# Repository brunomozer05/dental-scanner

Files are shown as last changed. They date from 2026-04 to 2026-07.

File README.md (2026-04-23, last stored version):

# DentalScanner

Aplicativo iOS nativo em Swift para capturar tags ArUco com a camera do iPhone, estimar a pose 3D dessas tags via fotogrametria/visao computacional e gerar um arquivo `.stl` com a posicao final das tags no espaco.

Este repositorio agora contem a fundacao do projeto:

- Arquitetura modular alinhada a captura ArUco + export STL
- App iOS em SwiftUI com fluxo demo de captura guiada
- Camada `DentalScannerKit` com Core, ArUco, Photogrammetry e Export
- Testes unitarios iniciais para validacao de sessao, tags, STL e fusao das poses
- GitHub Actions com geracao de projeto via XcodeGen
- Documentacao tecnica e assets de calibracao

Importante: esta primeira iteracao prioriza arquitetura, contratos e automacao. O backend real de deteccao ArUco via OpenCV e a estimacao/fusao de poses em producao ainda precisam ser conectados.

## Objetivo real do app

Fluxo esperado:

1. O usuario aponta a camera do iPhone para um conjunto de tags ArUco.
2. O app detecta as tags quadro a quadro.
3. O pipeline estima a pose 3D das tags e funde observacoes de multiplas vistas.
4. Ao finalizar, o app gera um `.stl` contendo a representacao 3D das tags nas posicoes estimadas.

Este projeto nao esta sendo tratado, neste momento, como uma reconstrucao detalhada de uma superficie odontologica. O foco da base atual passou a ser mapa 3D das tags ArUco.

## Requisitos de produto

- iOS 15.0+
- iPhone 8 ou superior
- Camera RGB 12 MP ou superior
- Sem uso de LiDAR
- Tags ArUco 4x4_50 ou 4x4_100 com 8 mm x 8 mm
- Meta de precisao final: +-100 um

## Estrutura do repositorio

```text
DentalScanner/
|- App/
|- UI/
|- Core/
|- ArUco/
|- Photogrammetry/
|- Export/
|- Shared/
|- Support/
Tests/
docs/
Resources/
.github/workflows/
project.yml
```

## Setup do ambiente

### Opcao 1: abrir em um Mac com Xcode

1. Instale Xcode 15.2 ou superior.
2. Instale XcodeGen:

```bash
brew install xcodegen
```

3. Gere o projeto:

```bash
xcodegen generate
```

4. Abra `DentalScanner.xcodeproj` no Xcode.
5. Rode o scheme `DentalScanner` em um simulador iPhone ou dispositivo fisico.

### Opcao 2: usar apenas GitHub Actions

O workflow em `.github/workflows/ios-build.yml`:

- instala Xcode 15.2
- instala XcodeGen
- gera o projeto
- roda build
- roda testes
- gera sempre um `.ipa` unsigned como artifact
- gera tambem um `.ipa` assinado quando os secrets de assinatura estiverem configurados

## Gerar `.ipa` no GitHub Actions

Agora existem dois formatos de artifact:

- `DentalScanner-IPA`: sempre gerado, no mesmo estilo do seu outro projeto, com `.ipa` unsigned
- `DentalScanner-Signed-IPA`: opcional, apenas quando os secrets de assinatura estiverem configurados

Importante: o `.ipa` unsigned serve para baixar o arquivo pronto do GitHub, mas nao instala diretamente no iPhone sem assinatura posterior.

### Secrets obrigatorios

Cadastre em `Settings > Secrets and variables > Actions`:

- `BUILD_CERTIFICATE_BASE64`: conteudo Base64 do certificado `.p12`
- `P12_PASSWORD`: senha do `.p12`
- `BUILD_PROVISION_PROFILE_BASE64`: conteudo Base64 do `.mobileprovision`
- `KEYCHAIN_PASSWORD`: senha temporaria do keychain usado no runner
- `APPLE_TEAM_ID`: Team ID da sua conta Apple Developer

### Variable opcional

Cadastre em `Settings > Secrets and variables > Actions > Variables`:

- `IOS_EXPORT_METHOD`: `development` ou `ad-hoc`

Se nada for definido, o workflow usa `development`.

### Como converter os arquivos para Base64

No Mac:

```bash
base64 -i Certificates.p12 | pbcopy
base64 -i Profile.mobileprovision | pbcopy
```

No Windows PowerShell:

```powershell
[Convert]::ToBase64String([IO.File]::ReadAllBytes("Certificates.p12"))
[Convert]::ToBase64String([IO.File]::ReadAllBytes("Profile.mobileprovision"))
```

### Requisitos para instalar no celular

- o `Bundle Identifier` do app precisa bater com o provisioning profile
- o iPhone precisa estar incluido no profile se o metodo for `development` ou `ad-hoc`
- o certificado precisa pertencer ao mesmo time Apple do profile

### Onde baixar o `.ipa`

Depois do workflow terminar:

1. abra a execucao no GitHub Actions
2. entre em `Artifacts`
3. baixe `DentalScanner-IPA` para o `.ipa` unsigned
4. se houver, baixe `DentalScanner-Signed-IPA` para o build assinado

O artifact inclui:

- um `.zip` gerado automaticamente pelo GitHub Actions

Dentro do `.zip` do artifact ficam:

- `DentalScanner.ipa`

No artifact assinado tambem pode haver:

- plist(s) de exportacao
- `DentalScanner.xcarchive`

### Como instalar

Com o `.ipa` assinado em maos, voce pode instalar via:

- Xcode
- Apple Configurator 2
- MDM
- TestFlight, se depois trocar o metodo para distribuicao adequada

## Como calibrar a camera

1. Imprima o tabuleiro `10x7` em escala conhecida.
2. Use iluminacao uniforme e evite reflexos especulares.
3. Capture de 30 a 50 imagens com variacao real de angulo e distancia.
4. Garanta o tabuleiro inteiro visivel em todos os frames.
5. Aceite a calibracao somente quando o erro medio de reprojecao ficar abaixo de `0.3 px`.
6. Persista a calibracao por dispositivo.

Assets de apoio:

- `Resources/CalibrationTargets/checkerboard_10x7.svg`
- `Resources/SampleCalibrationDataset/manifest.json`

## Como posicionar as tags ArUco

- Use 4 a 8 tags simultaneas.
- Tamanho fisico de cada tag: `8 mm x 8 mm`.
- Distribua as tags ao redor do fixture para manter pelo menos 4 visiveis em quase toda a orbita.
- Evite oclusao por dedos, pinas ou suportes.
- Mantenha as tags no mesmo plano de referencia global sempre que possivel.
- Prefira imprimir em material matte para reduzir reflexos.

## Fluxo de captura planejado

1. Carregar calibracao valida.
2. Posicionar o setup com as tags visiveis.
3. Capturar de 15 a 30 poses ao redor do conjunto de tags.
4. Garantir sobreposicao de 70-80% entre frames consecutivos.
5. Validar nitidez, blur, iluminacao e visibilidade de tags em tempo real.
6. Estimar e fundir as poses 3D das tags entre multiplos frames.
7. Gerar STL com a posicao final das tags + relatorio.

## Estado atual da implementacao

Ja implementado:

- `CameraEngine` com configuracao de captura de alta precisao via `AVFoundation`
- `CalibrationManager` para avaliar e persistir intrinsecos
- `SessionManager` com cobertura angular, quality gates e progresso
- `ArUcoDetector` com interface pronta para backend OpenCV
- `TagValidator` e `PoseEstimator`
- `MarkerSceneReconstructor` para fundir observacoes por ID de tag
- `MeshReconstructor` configurado para gerar malha STL das tags
- `STLExporter` e `MeasurementReportGenerator`
- UI demo em SwiftUI para provar o fluxo

Proximo passo tecnico obrigatorio:

- integrar um backend real de OpenCV para deteccao ArUco e `solvePnP`
- estimar pose 6DoF real por tag com intrinsecos calibrados
- fundir as poses entre multiplas imagens com rejeicao de outliers
- exportar o STL final direto no iPhone
- validar a consistencia espacial entre tags

## Debug mode recomendado

Manter um modo debug com:

- IDs das tags visiveis por frame
- score de nitidez
- score de overlap
- mapa de cobertura angular
- contagem de features detectadas
- pares aceitos/rejeitados no matching
- mapa de calor de erro no pos-processamento

## Troubleshooting

### Nao detecta tags

- Verifique impressao das tags.
- Aumente iluminacao difusa.
- Evite motion blur.
- Confirme se 4 ou mais tags estao inteiras no frame.

### Reconstrucao instavel

- Refaca a calibracao se o erro passar de `0.3 px`.
- Aumente a sobreposicao entre capturas.
- Capture em orbita mais lenta.
- Remova frames com brilho especular excessivo.

### Escala incorreta

- Confirme dimensao fisica real das tags.
- Verifique se o backend de pose usa pontos-objeto em milimetros.
- Rejeite tags com escala inconsistente.

### Build do CI falha

- Verifique se o `project.yml` foi atualizado junto com novos arquivos.
- Rode `xcodegen generate` antes do build local.
- Confirme a versao do Xcode no workflow.

## Documentacao tecnica

- [Pipeline de Fotogrametria](docs/photogrammetry-pipeline.md)
- [Estrategia de Precisao](docs/precision-strategy.md)
- [Formato de Dados](docs/data-format.md)

## Roadmap sugerido

1. MVP com deteccao ArUco e STL basico das tags
2. Integracao OpenCV + pose 6DoF real
3. Fusao robusta de poses entre multiplas vistas
4. Exportacao STL final no aparelho
5. Refinamento de precisao para meta de +-100 um

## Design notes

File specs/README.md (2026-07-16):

# DentalScanner Specs

Esta pasta contém as specs oficiais do projeto DentalScanner.

Antes de qualquer alteração no código, o agente deve ler:

1. `00_project_context.md`
2. `08_known_issues.md`
3. `09_next_tasks.md`
4. A spec específica da área que será alterada

Estas specs são a fonte de verdade do projeto.

## Indice

* `00_project_context.md` - contexto geral do projeto.
* `03_scan_pipeline.md` - pipeline principal de scan/export.
* `05_pose_quality_and_readiness.md` - qualidade de pose e readiness.
* `06_export_and_reports.md` - export STL e reports.
* `07_debug_panel.md` - regras do debug seguro.
* `08_known_issues.md` - problemas conhecidos.
* `09_next_tasks.md` - backlog tecnico.
* `10_best_final_pose_candidate.md` - plano futuro para exportar o melhor candidato de pose final.
* `11_device_quality_pipeline.md` - perfis por device, frame mask e quality diagnostics.
* `12_observation_quality_and_angle_diversity.md` - qualidade de observacoes e diversidade angular.
* `13_camera_resolution_focus_intrinsics.md` - camera, foco, resolucao e intrinsics.
* `14_marker_v3_and_robust_pnp.md` - marker futuro, pontos extras e PnP robusto.
* `15_validation_protocol_and_accuracy.md` - protocolo de validacao e limites das afirmacoes de accuracy.
* `16_frame_indexed_observations.md` - Frame Indexed Observation Model.
* `17_pre_accumulation_observation_gate.md` - Pre-Accumulation Observation Quality Gate.
* `18_scan_session_replay.md` - Scan Session Capture and Deterministic Replay.
* `19_frame_indexed_bundle_adjustment.md` - active frame-indexed bundle-adjustment investigation and implementation plan.
* `19_offline_frame_indexed_optimization.md` - historical optimizer roadmap, superseded by the detailed Spec 19A design.
* `20_capture_maturity_replay.md` - offline capture-maturity, angular-diversity, connectivity, and progress replay.

## Regras gerais

* Não reativar código antigo de debug que já causou crash.
* Não alterar OpenCV, solvePnP, STLExporter ou GitHub Actions sem necessidade explícita.
* Não copiar código, assets, modelos ou algoritmos de terceiros.
* Não usar arquivos de apps externos dentro do projeto.
* Manter o pipeline atual funcional.
* Toda alteração deve ser incremental, segura e fácil de reverter.
* Se algum dado for inválido, nil, NaN ou infinity, a UI deve mostrar `—`, nunca crashar.

## Ordem recomendada das próximas tarefas

1. Bloquear export STL se houver menos de 4 markers exportáveis.
2. Melhorar câmera/foco/sharpness.
3. Atualizar comparador Python para ler `_report.json`.
4. Comparar iPhone 11 vs iPhone 16 com dados objetivos.
5. Comparar marker v1 vs marker v2.
6. Avaliar marker v3 híbrido futuramente.
7. Adicionar ARKit Assist experimental.
8. Refinar final pose/export quality gates.

## Roadmap arquitetural frame-indexed

As specs 16–20 seguem a ordem abaixo. As fundações diagnostics/shadow 16–17, as phases 18A/18B, o replay offline ALL/Pre-Gate persistido e o export diagnóstico de STLs ALL/FILTERED em frame comum estão implementados. A Spec 20 adiciona validação offline de maturidade da captura antes de qualquer mudança no progresso ao vivo. A Spec 19A está especificada; validação física dos replays, blocking ao vivo e implementação 19B permanecem pendentes.

### Phase A

`16_frame_indexed_observations.md`

Criar a fundação diagnostics/read-only que preserva a associação entre frame, intrinsics, correspondências e pose por frame.

### Phase B

`17_pre_accumulation_observation_gate.md`

Avaliar e, atrás de feature flag desligada por padrão, impedir que observações rejeitadas entrem no acumulador primário.

### Phase C

`18_scan_session_replay.md`

Persistir sessões geométricas versionadas para replay determinístico e comparação A/B sobre os mesmos dados.

### Offline maturity checkpoint

`20_capture_maturity_replay.md`

Reproduzir offline a maturidade por marker e global sobre o mesmo schema-1, separando observações ALL/FILTERED, vistas distintas, cobertura, conectividade e timeline. `STRICT` permanece o resultado principal; um modo `REFERENCE_LIKE` documenta relaxamento adaptado sem afirmar a fórmula protegida da referência.

Esse diagnóstico deve ser executado sobre sessões físicas antes de alterar a barra ao vivo ou escolher a população de frames da futura Spec 19C. Ele não implementa BA e não conclui 19B.

### Phase D

`19_frame_indexed_bundle_adjustment.md`

Investigar, especificar e depois comparar offline o acumulador atual com um bundle adjustment que mantém uma pose de câmera por frame e uma pose compartilhada por marker. A implementação começa em 19B somente após revisão da Spec 19A; qualquer população selecionada pelo replay de maturidade exige validação física antes de virar uma política da futura 19C.

Somente depois dessas validações avaliar integração primária de diversidade angular, pose graph, marker v3 e otimização global.

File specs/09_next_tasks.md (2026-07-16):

# 09 — Next Tasks

## Prioridade 1 — Bloquear export com menos de 4 markers

Problema:

```txt
às vezes o app exporta STL com 3 markers mesmo parecendo ter escaneado 4.
```

Tarefa:

* separar visual markers de exportable markers;
* definir `expectedPhysicalMarkerCount = 4`;
* bloquear export se `exportableMarkers.count < 4`;
* mostrar erro claro;
* mostrar markers faltando;
* atualizar report JSON.

Commit sugerido:

```txt
Block STL export when markers are missing
```

## Prioridade 2 — Atualizar comparador Python para ler `_report.json`

Tarefa:

* carregar reports junto com STLs;
* comparar poses por marker;
* mostrar qualidade por scan;
* mostrar missing markers;
* mostrar focus/sharpness;
* cruzar erro STL com qualidade reportada.

## Prioridade 3 — Melhorar câmera/foco/sharpness

Tarefa:

* wide física fixa;
* zoom digital controlado;
* foco manual;
* foco guiado por ArUco;
* lock after focus;
* sharpness/blur score;
* rejeitar frames fora de foco;
* debug camera/focus.

## Prioridade 4 — Testes iPhone 11 vs iPhone 16

Fazer pastas:

```txt
tests/iphone11_perto
tests/iphone11_longe
tests/iphone16_auto_focus
tests/iphone16_focus_locked
```

Para cada teste:

* 3 a 5 scans;
* guardar STL;
* guardar report JSON;
* rodar comparador;
* anotar distância/foco/zoom/configs.

Adicionar tambem testes por `cameraProfileId`:

```txt
Default
Wide 1.0x
Wide 1.5x
Wide 2.0x
Wide 1.5x Conservative Focus
Wide 2.0x Conservative Focus
```

Nos testes iniciais do iPhone 16:

* priorizar `Wide 1.5x` como recomendado para `iPhone17,*`;
* testar distância ideal inicial de 150-180 mm;
* evitar ficar abaixo de 120-125 mm, pois aumenta risco de perda de foco;
* manter `Wide 2.0x` e `Wide 2.0x Conservative Focus` como experimentais/não recomendados até nova evidência.
* confirmar no app que a barra lateral de distancia mostra 150-180 mm dentro da faixa verde e usa escala dinamica do perfil.

Proxima etapa futura:

```txt
Auto Camera Profile Evaluation
```

Esse modo deve testar perfis por uma janela curta e escolher o melhor usando:

* markerDetectionRate;
* averageSharpness;
* averageReprojection;
* poseQuality;
* focusLostCount;
* relativeMarkerDistanceStdMean;
* relativeMarkerDistanceStdMax.

Nao automatizar antes de comparar resultados por aparelho/perfil nos reports.

Fases ja implementadas como diagnostics/read-only:

```txt
DeviceQualityProfile por classe de device
Frame Mask / ROI Quality Diagnostics
Experimental Quality Mode com observacoes uteis em paralelo
```

Ainda pendente:

* validar os contadores de observacoes uteis contra CSVs e scans reais;
* adicionar diagnostics completos de diversidade angular;
* adicionar PnP robustness diagnostics;
* atualizar o comparador para expor os novos campos;
* decidir, com dados, se ROI/observacao util vira soft gate.

O replay offline de maturidade da Spec 20 agora separa observações válidas, vistas distintas, frames selecionados, conectividade e o alvo global de 300 frames. Os valores de 65/1,5°/4,5°/300 permanecem parâmetros diagnósticos com proveniência explícita e não alteram export, readiness, finalização ou progresso ao vivo.

High Resolution Camera Profile esta preparado para teste manual e permanece desligado por padrao. Quando `Wide 1.5x High Resolution Experimental` for selecionado manualmente, o app deve tentar 3840x2160 e registrar fallback se o formato nao estiver disponivel.

Reference Camera Matrix Diagnostics e read-only e nao substitui os intrinsics reais da camera.

## Prioridade 5 — Comparar v1 vs v2

Objetivo:

Decidir se o `dualArucoV2` realmente melhora.

Se v1 for mais consistente, considerar voltar foco para v1 ou criar v3 híbrido.

## Prioridade 6 — ARKit Assist experimental

Adicionar ARKit como diagnóstico/quality score, não substituição.

Padrão desligado.

Usar para:

* tracking state;
* camera transform;
* intrinsics;
* motion;
* light estimate;
* penalizar frames ruins.

## Prioridade 7 — Final refinement mais rígido

Tarefa:

* usar quality score centralizado;
* rejeitar blur/foco;
* rejeitar missing markers;
* normal outlier;
* pesos separados posição/rotação;
* confiança final por marker.

## Prioridade 8 — Marker v3 híbrido

Futuro:

```txt
1 ArUco maior
+ bolinhas/pontos
+ fundo branco
+ elementos pretos
```

Não implementar antes de estabilizar v1/v2 e câmera.

## Tarefa futura - Best Final Pose Candidate

Implementar a spec `10_best_final_pose_candidate.md`.

Objetivo:

* durante o refinamento apos 4 markers em 100%, avaliar candidatos com throttle;
* salvar o melhor conjunto de poses final encontrado;
* exportar usando esse melhor candidato quando valido;
* manter fallback seguro para o fluxo atual;
* registrar uso, score, idade e metricas do candidato em diagnostics/report;
* expor campos simples no debug emergencial.

Commit sugerido:

```txt
Add best final pose candidate tracking
```
## Task - Validate high resolution frame processing

Run side-by-side scans with `Wide 1.5x` and
`Wide 1.5x High Resolution Experimental`.

Use the new diagnostics to compare:

```txt
cameraFramePixelBufferWidth/Height
cameraFrameProcessingWidth/Height
cameraFramesReceived/Processed/Dropped
cameraLastFrameProcessingMs
cameraAverageFrameProcessingMs
arucoDetectedMarkerCountLastFrame
arucoDetectedExpectedMarkerCountLastFrame
arucoFramesWithAnyMarkerCount
arucoFramesWithExpectedMarkerCount
poseAcceptedLastFrame
poseRejectedLastFrame
poseLastRejectReason
```

Only consider downscale or intrinsics/corner scaling if the diagnostics prove
that 4K frames arrive but detection or pose acceptance fails.

## Roadmap arquitetural — observações e otimização multi-frame

As próximas fundações arquiteturais devem ser executadas em commits separados. A primeira fase diagnostics-only da Phase A, o shadow diagnostics da Phase B, as fases 18A/18B da Phase C e os replays offline A/B estão implementados. Blocking ao vivo permanece desligado. A Spec 20 fornece o checkpoint offline de maturidade da captura; a implementação BA da Phase D permanece pendente.

### Phase A — Spec 16

`16_frame_indexed_observations.md`

Adicionar um modelo de observação por frame, inicialmente diagnostics/read-only, preservando:

```txt
frame index e timestamp
intrinsics e dimensões do frame
observações por marker
correspondências 2D/3D
pose individual por frame
quality metadata
```

Não alterar acumulador, readiness, finalization ou export nessa fase.

Status: primeira fase diagnostics-only implementada em 2026-07-12, com modelo explícito por frame, buffer limitado, diagnostics agregados e reset de sessão. A captura full-session passou à Phase 18A; reader/replay e qualquer consumo pelo pipeline primário permanecem pendentes.

### Phase B — Spec 17

`17_pre_accumulation_observation_gate.md`

Criar um quality gate antes da inserção no `MultiFramePoseAccumulator`, primeiro em shadow mode e depois atrás de feature flag desligada por padrão.

Comparar obrigatoriamente:

```txt
gate OFF
gate ON
```

Diversidade angular não entra no primeiro commit dessa fase.

Status: shadow diagnostics implementado em 2026-07-12. O gate avalia antes do accumulator e registra decisões/comparação pareada. O replay offline ALL versus decisões persistidas `wouldAccept` foi implementado, mas blocking ao vivo permanece desligado e sua validação física continua pendente.

### Phase C — Spec 18

`18_scan_session_replay.md`

Persistir somente geometria e quality metadata suficientes para replay determinístico. Não salvar frames completos por padrão e não alterar o comparador Python nesta fase.

Status: Phase 18A de captura progressiva full-session, Phase 18B de reader/replay determinístico, replay diagnóstico ALL versus Pre-Gate aceito persistido e export de STLs diagnósticos normalizados em um marker-base comum implementados. Cada modo prova determinismo com accumulators novos; a comparação produz geometria relativa, dois STLs separados e manifest sem alterar o STL normal. Validação física, integração com comparador e optimizer continuam pendentes.

### Capture maturity checkpoint — Spec 20

`20_capture_maturity_replay.md`

Executar sobre o mesmo schema-1 um replay exclusivamente offline que mede:

```txt
observações ALL e FILTERED
vistas distintas por marker
redundância
dispersão e cobertura angular
seleção de frames e observações
conectividade frame-marker
marker limitante
timeline e maturidade global
```

`STRICT` não relaxa thresholds e é o resultado principal. `REFERENCE_LIKE` é uma adaptação secundária com histórico explícito; não reproduz como fato uma fórmula protegida da referência. O progresso diagnóstico nunca chega a 100% antes da maturidade global.

Status: implementação diagnóstica/offline e ação on-device introduzidas pela Spec 20. Validação sobre `Scan_2026-07-16_12-30_session.ndjson` permanece pendente e o artifact físico não entra no Git. Não alterar a UI ao vivo antes dessa validação.

### Phase D — Spec 19

`19_frame_indexed_bundle_adjustment.md`

Executar experimento A/B offline:

```txt
A = MultiFramePoseAccumulator atual
B = otimizador com uma pose de câmera por frame e uma pose compartilhada por marker
```

Manter intrinsics fixos e usar residual reprojetivo robusto na primeira versão. O resultado B não controla export.

Status: Spec 19A de investigação e desenho concluída. Convenções de coordenadas, gauge, inicialização por conectividade, residual, políticas ALL/FILTERED, decisão de solver, falhas, métricas e fases 19B–19G estão especificadas. A infraestrutura pré-BA de export STL diagnóstico ALL/FILTERED está disponível para reutilização futura, mas núcleo matemático, adapter NDJSON, BA, A/B físico e a fase 19F accumulator-versus-BA permanecem não implementados e pendentes de revisão.

A Spec 20 pode informar futuramente a política de seleção da Phase 19C, mas maturidade de captura, seleção de observações e otimização geométrica permanecem decisões separadas. A Phase 19B continua pendente; nenhum resultado da Spec 20 é entrada automática do BA.

### Depois das phases A–D

Avaliar, em tarefas/specs separadas:

1. integração primária de diversidade angular por marker;
2. pose graph;
3. marker v3 e pontos extras próprios;
4. otimização global e eventual viabilidade runtime.

As fundações frame-indexed, o replay determinístico e o replay offline de maturidade existem. Primeiro revisar a evidência física de maturidade; implementar bundle adjustment somente pelas fases revisadas da Spec 19. Pose graph e otimização de focal/distorção continuam fora do primeiro BA.

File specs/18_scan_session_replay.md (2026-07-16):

# 18 — Scan Session Capture and Deterministic Replay

## Status

Phase 18A full-session progressive observation capture, Phase 18B deterministic current-accumulator replay, diagnostics-only persisted Pre-Gate ALL/FILTERED A/B replay, common-frame diagnostic STL comparison export, and offline capture-maturity replay are implemented. Saved-scan actions execute replay off the main thread and export Codable JSON summaries or separately named diagnostic artifacts.

Physical Pre-Gate A/B and capture-maturity validation, any live blocking/progress decision, comparator integration, and offline optimizer integration remain pending. Capture and replay are diagnostic/offline infrastructure and do not create a new production scan pipeline.

## Goal

Persist enough geometric and quality information to reproduce a scan session deterministically without saving full camera frames by default.

The same captured session should be usable to compare the current accumulator, the new quality gate, future angle-diversity selection, and an offline optimizer without asking the operator to repeat the physical scan.

## Dependencies

- Spec 16 provides the frame-indexed observation model.
- Spec 17 defines optional gate classifications and counters.
- Spec 19 consumes replay data for offline A/B optimization.

Replay capture must not require specs 17 or 19 to be enabled.

## Versioned session schema — Phase 18A

Phase 18A uses NDJSON / JSON Lines with one independently encoded object per line. Every record has `recordType` and `schemaVersion`; schema version 1 defines these record types:

```txt
sessionHeader
frameObservation
sessionFooter
```

The header records a session identifier, capture-start timestamp, device model identifier, OS version, camera profile identifier/name, marker profile, expected physical marker IDs, relevant capture/gate feature flags, app version, app build identifier, and an optional app Git commit hash. The commit hash is populated only when reliable build provenance is injected into `AppGitCommitHash`; the current project does not inject it, so this field is normally absent rather than inferred from a development machine.

Each frame record must include, when available:

```txt
frameIndex
timestamp
frameWidth
frameHeight
intrinsics
camera profile metadata
marker observations
frame quality metadata
```

Each marker record must include:

```txt
markerId
markerProfile
stable pose-source identifier and associated fallback tag ID when applicable
2D image correspondences
3D object correspondences
per-frame pose
explicit rotation-matrix rows used by the current accumulator
reprojection error
distance
marker area in pixels
used point count
detected top/bottom tag IDs when applicable
frame-mask state
focus quality
motion quality
finite/valid state
gate classification and reason
```

The schema must not contain credentials, tokens, passwords, private endpoints, local filesystem paths, or unrelated user/account information.

## Storage decision

Phase 18A uses progressive NDJSON rather than a single JSON array. This keeps the artifact inspectable while avoiding full-session retention in memory. Header, frame, and footer lines are written in enqueue order by a private serial writer queue.

Requirements:

- stable field names;
- explicit schema version;
- persisted frame ordering is enqueue ordering; marker and 2D/3D point order are preserved exactly from the authoritative `FrameObservation`;
- non-finite numeric values are encoded using explicit `NaN`, `Infinity`, and `-Infinity` strings where a non-optional diagnostic field can contain them;
- optional fields for unavailable metadata;
- documented units and coordinate conventions.

If real sessions prove JSON too large or slow, a future binary encoding may be added behind a new schema/container version. The semantic schema and compatibility rules must remain independent of the encoding.

## Bounded file size

Control size through data selection, not by silently dropping arbitrary fields.

The current 600-frame `FrameObservationRecorder` buffer from spec 16 remains a rolling diagnostics buffer only. It is not the authoritative full-session replay store. Phase 18A adds a separate progressive writer that receives the same authoritative immutable observation before the unchanged accumulator update.

- No full camera images by default.
- No `CVPixelBuffer`, video, thumbnails, or external assets.
- Reuse the numeric-only observation model and explicit bounds from spec 16 without treating its rolling buffer as complete session history.
- The progressive writer does not evict persisted frames.
- The schema-1 hard limit is 128 MiB, with footer space reserved. A numeric observation is expected to be roughly 2–8 KiB; at up to approximately 9,000 processed frames in a five-minute 30 FPS session this is approximately 18–72 MiB, leaving conservative headroom without allowing unbounded storage.
- If the limit or bounded writer backlog is exceeded, capture stops accepting frames, remains incomplete, and reports an integrity failure without affecting the primary scan.
- Optional compression may be evaluated later without changing replay semantics.

## Deterministic replay

Given the same session file, app commit, replay configuration, and algorithm version, replay must produce the same ordered inputs and deterministic outputs within documented floating-point tolerance.

Replay must control or record:

```txt
algorithm configuration
feature flags
marker ordering
frame ordering
threshold sources
random seeds, if any
floating-point/backend identifier when relevant
```

The replay runner must not access the live camera, current device intrinsics, wall-clock timing, or mutable UI state as hidden inputs.

Phase 18A records the complete numeric `PoseResult` inputs currently consumed by `MultiFramePoseAccumulator`: marker/profile/source identity, rotation vector, the exact rotation-matrix rows supplied to the accumulator, translation vector, reprojection error, distance, marker area, used point count, and detected tag IDs. The future reader must validate the matrix shape and use the explicit matrix rather than silently recomputing a potentially numerically different value from Rodrigues data.

The remaining provenance caveat is that `appGitCommitHash` is optional until build tooling injects reliable commit metadata. A replay reader must report that gap and must not substitute the Git HEAD of the machine running the reader.

## Phase 18B reader and current-accumulator replay

Phase 18B provides a streaming schema-1 NDJSON reader. It reads bounded chunks, decodes one non-empty line at a time, preserves physical file order, and never sorts frames or marker observations.

The default deterministic path requires:

- one supported schema-1 header as the first non-empty record;
- strictly increasing frame indices;
- finite available capture timestamps preserved in file order (timestamps are not used as a second ordering key);
- one footer as the last non-empty record;
- `completed = true`;
- footer frame counts matching decoded records;
- zero writer failures and order violations;
- no file-size-limit truncation;
- footer `fileSizeBytes` matching the artifact.

Incomplete captures may be opened only through an explicit diagnostic option. Integrity errors throw and never return a partial replay result.

Each marker observation is reconstructed into `PoseResult` using persisted values only. The persisted three `rotationMatrixRows` are shape-checked, finite-checked, and passed explicitly to the `PoseResult` initializer. The replay path does not call PnP, Rodrigues conversion, image-point pose estimation, or current device/camera APIs.

The runner opens the file twice. Each pass creates a fresh reader and fresh `MultiFramePoseAccumulator(scannerDefault)`, then calls `update(with:)` exactly once per frame record, including frames with an empty pose array. There is no random input in the current accumulator.

Replay A and Replay B final poses are compared by marker using translation distance and the angular magnitude of the relative rotation matrix. Determinism tolerances are:

```txt
translation: 1e-9 mm
rotation: 1e-9 degrees
```

The machine-readable replay summary records provenance, counts, final marker/pose summaries, per-marker A/B deltas, aggregate deltas, tolerances, and `replayDeterministic`.

Schema 1 does not persist the exact final live `MultiFramePoseAccumulator` state. Downstream export/final-refinement poses are not semantically equivalent, so direct live-vs-replay comparison remains unavailable.

## Persisted Pre-Accumulation Gate A/B replay

The diagnostics-only A/B runner executes four fresh accumulator passes over the same schema-1 session:

```txt
ALL-A / ALL-B
  all persisted marker observations

FILTERED-A / FILTERED-B
  only observations with persisted
  preAccumulationGateEvaluated == true and
  preAccumulationGateWouldAccept == true
```

The filtered policy never calls the gate implementation again and never reconstructs thresholds from historical quality metadata. A missing evaluation or missing accept/reject decision fails filtered replay with frame and marker identity. A persisted rejection without a reject reason remains replayable but is reported as an annotation-integrity inconsistency.

Every persisted frame produces one accumulator update in both policies, including `update(with: [])` when a filtered frame has no accepted observations. Marker order among retained observations remains physical file order.

ALL and FILTERED determinism are verified independently. Their primary geometry comparison is not the raw globally anchored pose delta. For each common unordered marker pair `(A, B)`, replay computes:

```txt
R_AB = transpose(R_A) * R_B
t_AB = transpose(R_A) * (t_B - t_A)
```

It compares pair distance and relative rotation between modes. This cancels each result's global/anchor frame. An identity pose for the accumulator anchor, including M0 when selected as anchor, is not evidence that marker quality improved or remained unchanged.

The A/B summary records global/per-marker selection counts, persisted reject-reason counts, annotation inconsistencies, independent determinism summaries, both final pose sets, pairwise relative geometry, capture provenance, and the captured live blocking flag. It emits measurements only and no better/worse verdict.

## Diagnostic replay STL comparison

The saved-scan diagnostic action may reuse the persisted Pre-Gate A/B runner to create visual comparison artifacts without enabling live blocking. Export is allowed only after both ALL and FILTERED pass their independent Replay A/Replay B determinism checks.

`MultiFramePoseAccumulator` results are output-frame-from-marker poses, but ALL and FILTERED may have selected different accumulator anchors. Before STL generation, both pose sets are independently rebased to the lowest common marker ID:

```txt
T_base_marker = inverse(T_output_base) * T_output_marker
```

The chosen base becomes identity in both sets. This changes only each set's output coordinate frame and preserves its internal marker distances and relative rotations. Absence of a common marker is an explicit failure; no marker ID, including M0, receives special handling.

The diagnostic exporter delegates model lookup, marker-local axis mapping, triangle transformation, marker ordering, and ASCII STL serialization to the existing `STLExporter`. It writes, atomically per artifact:

```txt
<scan>_replay_all.stl
<scan>_replay_pregate_filtered.stl
<scan>_replay_stl_comparison.json
```

The manifest records capture provenance, policies, determinism, marker sets, common base, STL filenames/sizes, pairwise relative geometry, coordinate normalization, persisted-decision use, captured live blocking flag, integrity, and caveats. It never declares either mode better. The saved production STL, source NDJSON, reports, diagnostics, and existing replay summaries are not modified.

## Capture lifecycle — Phase 18A

```txt
new scan
  -> create a unique *_session.ndjson file in the existing scan Documents storage
  -> enqueue sessionHeader

authoritative FrameObservation
  -> rolling diagnostics recorder
  -> progressive session writer enqueue
  -> unchanged MultiFramePoseAccumulator.update input

successful completion
  -> drain previously queued frame records
  -> write sessionFooter
  -> synchronize and close
  -> mark capture completed

reset, cancel, camera stop, or camera error
  -> drain previously queued frame records
  -> write sessionFooter with completed = false when possible
  -> synchronize and close
```

The writer tracks enqueued/written frame indices and treats a non-increasing enqueue index as an integrity violation. It never silently sorts observations. Capture failures remain non-fatal to readiness, finalization geometry, STL generation, and export.

## Compatibility

- New readers must reject unknown major schema versions clearly.
- New readers should accept older supported versions using defaults for missing optional fields.
- Existing fields must not change meaning in place.
- Units and coordinate frames must be versioned if they change.
- Migration must be deterministic and tested with committed synthetic fixtures, not private scan data.
- Unsupported records must fail with diagnostics rather than partial silent replay.

## Security and privacy

Replay files must contain only technical scan geometry and quality metadata needed for experiments.

Do not store:

- credentials or authentication material;
- private URLs;
- proprietary external models/assets/geometries;
- full images by default;
- local reference paths;
- account metadata.

Any future optional image capture requires a separate explicit privacy/storage design.

## Comparison targets

The same replay should be able to evaluate:

```txt
current MultiFramePoseAccumulator
pre-accumulation gate OFF/ON
offline per-marker capture maturity and angle diversity
offline frame-indexed optimizer
```

Each result must identify the algorithm/configuration version that produced it.

## Offline capture-maturity replay

Spec 20 reuses the schema-1 reader to evaluate capture support without changing current-accumulator replay semantics. An immutable complete-observation callback exposes the decoded `FrameObservation` plus the exact selected marker/`PoseResult` pairs. Existing readers retain their strict missing-gate behavior; the maturity consumer may diagnose and exclude missing persisted gate annotations from `FILTERED` without inferring a decision.

The consumer runs two populations:

```txt
ALL
  every persisted observation that can be structurally reconstructed

FILTERED
  only persisted observations where:
  preAccumulationGateEvaluated == true
  preAccumulationGateWouldAccept == true
```

It does not re-run the Pre-Gate. Physical frame order, marker order/multiplicity, frame timestamps, and explicit persisted pose matrices remain authoritative.

Each population produces:

```txt
STRICT
  fixed thresholds; primary result

REFERENCE_LIKE
  bounded connectivity-conditioned relaxation; adapted secondary result
```

The maturity artifact contains per-marker histories, selected versus redundant views, angular spread, diagnostic coverage bins, valid/selected frame-marker connectivity, slowest-marker state, a deterministic 0.5-second timeline, and optional comparison with associated live diagnostics. It never updates the accumulator or exports geometry.

The default experimental values are documented with provenance in Spec 20:

```txt
minimum valid observations per marker    65
minimum distinct views per marker        65 (DentalScanner adaptation)
minimum distinct-view angle              1.5 deg
target angular spread                     4.5 deg
global selected-frame target              300
```

The `65 distinct views` interpretation, spherical RMS formula, coverage bins, and exact `REFERENCE_LIKE` schedule are original diagnostics. They are not represented as protected reference implementation details.

On-device output:

```txt
<scan-basename>_capture_maturity_replay.json
```

The file is deterministically encoded with sorted keys and shared separately. It does not overwrite the session NDJSON, scan STL, reports, diagnostics, replay summaries, or STL-comparison artifacts.

## CLI and comparator follow-up

A future CLI may:

- validate session schema;
- replay an algorithm configuration;
- export metrics in machine-readable form;
- compare A/B results;
- integrate with the existing comparator.

CLI and comparator implementation are follow-up work. This spec does not authorize changing the current Python comparator.

## Implementation order

1. **Implemented:** schema-1 progressive NDJSON capture behind `enableScanSessionObservationCapture = true` for the experimental development phase.
2. **Implemented:** committed synthetic schema fixtures, streaming reader validation, exact `PoseResult` reconstruction, and current-accumulator replay.
3. **Implemented:** fresh Replay A/Replay B execution and geometric determinism summary.
4. **Implemented:** diagnostics-only on-device execution for a saved scan with an associated session capture, including JSON summary export/share. Physical-session execution and inspection remain an operator validation step.
5. Add broader old-schema compatibility only when a second supported schema exists; unknown schemas already fail explicitly.
6. **Implemented:** persisted Pre-Gate ALL versus accepted-only A/B replay with independent determinism checks, pairwise relative geometry, and on-device JSON export.
7. **Implemented:** deterministic common-frame diagnostic STL export for ALL versus persisted Pre-Gate FILTERED, with a Codable comparison manifest and three-file share action.
8. **Implemented:** offline capture-maturity replay for ALL/FILTERED and STRICT/REFERENCE_LIKE, including deterministic timeline/connectivity diagnostics and a saved-scan JSON share action.
9. Perform physical visual A/B and capture-maturity validation before any live blocking or live-progress decision.
10. Add comparator and offline optimizer consumers only in their own phases.

## Acceptance criteria

- Phase 18A session files include schema, session, build, device, camera-profile, marker-profile, and expected-marker identity; commit provenance is optional until reliably injected.
- Frame and marker observations preserve ownership and coordinate conventions.
- Full camera images are absent by default.
- File size is bounded and truncation/eviction is reported.
- The same valid session can be replayed twice from fresh state and compared within documented tolerance.
- Capture maturity preserves complete frame/marker identity, diagnoses redundant viewpoints and connectivity, and never reaches diagnostic 100% before global maturity.
- STRICT remains unchanged by any REFERENCE_LIKE relaxation.
- Missing persisted gate annotations are diagnosed and never inferred for FILTERED maturity.
- Older supported schemas remain readable.
- Unknown schemas fail clearly.
- No credentials, private URLs, local paths, or external proprietary material are stored.
- Live scan, readiness, finalization, export, and comparator behavior remain unchanged.

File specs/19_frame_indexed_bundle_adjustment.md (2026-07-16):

# 19 — Frame Indexed Bundle Adjustment

## Status

Spec 19A investigation and design complete. Implementation is pending review. Spec 20 capture-maturity replay is a pre-BA diagnostic checkpoint; it does not implement or complete 19B.

This document supersedes `19_offline_frame_indexed_optimization.md` as the active design. The earlier document remains a historical roadmap overview.

## 1. Objective

Define an offline, diagnostics-only bundle-adjustment (BA) experiment without unstated assumptions. The first optimizer compares:

```txt
A = current MultiFramePoseAccumulator replay result
B = frame-indexed bundle-adjustment result
```

Optimizer B has one camera pose per selected frame, one shared global pose per marker, fixed intrinsics per frame, persisted ordered 2D/3D correspondences, a 2D reprojection residual, Huber loss, and one explicitly fixed gauge. It is replay-only and does not control live accumulation, readiness, finalization, or normal export.

Capture maturity, observation selection, and geometric optimization are separate layers. Spec 20 may provide measured candidate memberships for later 19C/19E experiments, but no maturity result automatically becomes BA input.

## 2. Authorization and reference scope

The authorized local external technical reference may inform mathematical conventions, solver trade-offs, and original DentalScanner design.

- `_local_reference/` remains read-only and untracked.
- No credential, private endpoint, authentication material, physical capture, binary, model, asset, or proprietary geometry enters the repository.
- No runtime dependency on the reference is permitted.
- Third-party components must be identified, independently licensed, and independently built.
- Findings use `CONFIRMED BY IMPLEMENTATION`, `CONFIRMED BY SYMBOL`, `STRONG INDICATION`, `INFERENCE`, or `UNCERTAIN`.
- DentalScanner remains self-contained and independently testable.

## 3. Confirmed reference architecture

The reference executable is an unstripped, encrypted arm64 iOS Mach-O. Symbols and packaged configuration are readable, but the relevant instructions cannot be reliably inspected. Symbols establish architecture, not multiplication or call order.

| Finding | Evidence | Classification |
|---|---|---|
| Optimization consumes a frame container | `OptimizeLogic::Run(FrameContainer const&, unsigned long)` | CONFIRMED BY SYMBOL |
| Camera state is indexed by frame | `InitializeVwcByFrameFromBaseMarker`, `InitializeVwcForFrame`, `RecomputeVwcByPnP`, `MarkerSourceFrameIndex` | CONFIRMED BY SYMBOL |
| Marker state is shared by marker ID | `InitializeVwmByIdFromFrames`, `UpdateVwmByIdFromFrame` | CONFIRMED BY SYMBOL |
| Reprojection residuals enter a Ceres problem | `AddReprojectionResiduals(ceres::Problem&, ceres::LossFunction*)`, `ComputeReprojectionResidual` | CONFIRMED BY SYMBOL |
| A residual has two 6-value pose blocks and one 4-value intrinsics block | `AutoDiffCostFunction<ReprojectionErrorSimpleRadial, 2, 6, 6, 4>` | CONFIRMED BY SYMBOL |
| Pose blocks use angle-axis operations | instantiated Ceres angle-axis conversions adjacent to those residuals | STRONG INDICATION |
| Robust Huber loss is present | `ceres::HuberLoss`; configured `kHuberLossDelta = 1.0` | CONFIRMED BY SYMBOL / CONFIG |
| A parameter block is fixed | `ceres::Problem::SetParameterBlockConstant` | CONFIRMED BY SYMBOL |
| Relative marker edges are an additional path | `BuildRelativeEdges`; `AutoDiffCostFunction<MarkerEdgeCost, 6, 6, 6>` | CONFIRMED BY SYMBOL |
| Later rejection/re-estimation exists | `RemoveOutliers`, `RecomputeVwcByPnP`, `RobustAverageVbm` | CONFIRMED BY SYMBOL |
| BA diagnostics include marker reprojection stats | `BAReport`, `MarkerReprojStats`, marker-pose serialization | CONFIRMED BY SYMBOL |
| Reference BA allows a simple radial camera model | 4-value intrinsics block, `ReprojectionErrorSimpleRadial`, focal/radial bounds | STRONG INDICATION |
| BA/graph limits are 150/100 iterations | packaged `BAConfig` | CONFIRMED BY CONFIG |

The app contains Ceres symbols in its main executable but no Ceres dylib, headers, sources, static archive, or build scripts. This strongly indicates static linkage. The encrypted app binary is not a reusable dependency; its exact Ceres version and build options are unknown.

Unknown by implementation: residual multiplication order; order of the four intrinsics values; fixed block identity; solver options; initialization fallback order; exact graph/BA/outlier/PnP/averaging call order; and whether every packaged value is active.

## 4. Coordinate conventions

### Reference assessment

All observed symbols are consistent with:

```txt
Vcm = camera-from-marker
Vwc = world-from-camera
Vwm = world-from-marker
Vcw = camera-from-world = inverse(Vwc)

p_world  = Vwm * p_marker
p_world  = Vwc * p_camera
p_camera = Vcw * p_world
Vcm      = inverse(Vwc) * Vwm
p_camera = inverse(Vwc) * Vwm * p_marker

Vwc_i = Vwm_j * inverse(Vcm_ij)
Vwm_j = Vwc_i * Vcm_ij
```

`Vcm` is passed to a screen-space projection symbol with marker points: `CONFIRMED BY SYMBOL` that it is the direct marker projection transform, with its direction a `STRONG INDICATION`. Paired `ComputeVcw`/`GetVwc`, plus `PredictVcm`, `GetVwm`, and initialization symbols provide a `STRONG INDICATION` for the remaining convention. It is `UNCERTAIN` at implementation level because the instructions are encrypted.

### Confirmed DentalScanner convention

DentalScanner passes marker-local millimetre object points and the returned rotation/translation directly to OpenCV `projectPoints`. Thus persisted `PoseResult` is:

```txt
T_cm,ij = camera-from-marker
p_c = R_cm,ij * p_m + t_cm,ij
```

This is `CONFIRMED BY IMPLEMENTATION` in `OpenCVArucoPoseBridge.mm`.

### DentalScanner BA contract

```txt
T_wc,i = world-from-camera for frame i
T_wm,j = world-from-marker j
T_cw,i = inverse(T_wc,i)
T_cm,ij = T_cw,i * T_wm,j

R_cm,ij = transpose(R_wc,i) * R_wm,j
t_cm,ij = transpose(R_wc,i) * (t_wm,j - t_wc,i)
p_c     = R_cm,ij * p_m + t_cm,ij
```

Object points/translations are millimetres; rotations are radians; image/intrinsics/residuals are pixels. Frame index is identity, timestamp is metadata, and Euler angles are forbidden.

## 5. DentalScanner current inputs

Schema 1 persists frame index/timestamp, frame dimensions, per-frame `fx/fy/cx/cy`, camera/marker profiles, ordered marker observations, ordered 2D/3D points, per-frame PnP vector/matrix/translation, reprojection/distance/area/point count/source/tag identity, quality metadata, and Pre-Gate shadow decisions.

The replay infrastructure now exposes an immutable complete-observation callback for Spec 20 while retaining existing replay behavior. Spec 19C may reuse that callback, but still needs a dedicated schema-1-to-BA problem adapter that validates intrinsics/correspondences and builds BA entities. It must not infer them from `PoseResult` or alter live replay.

The explicit persisted rotation matrix is authoritative for initialization. Validate it as finite and approximately in SO(3), convert it once to the chosen solver representation, and report disagreement with the persisted rotation vector. Do not run PnP or regenerate the matrix from that vector.

### Entities

#### `BundleAdjustmentCameraIntrinsics`

- identity: owning `frameIndex`;
- constants: `fx`, `fy`, `cx`, `cy`, width, height (pixels);
- lifecycle: decode/validate before problem construction; fixed during solve;
- validation: finite, `fx > 0`, `fy > 0`, and positive dimensions. The first builder does not reject a finite principal point merely for lying outside the image; it records that condition as a calibration-risk diagnostic.

#### `BundleAdjustmentFrameState`

- identity: unique persisted `frameIndex`; metadata: timestamp/file order;
- input: intrinsics and incident observations;
- variable: `T_wc,i`; constants: identity, time, intrinsics, dimensions;
- lifecycle: graph -> initialization -> optimization -> result;
- validation: increasing identity, finite initial pose, at least one retained edge.

#### `BundleAdjustmentMarkerState`

- identity: physical `markerId` plus compatible profile;
- input: incident observations and per-frame `T_cm,ij` estimates;
- variable: shared `T_wm,j`, except fixed gauge marker;
- constants: identity/profile/gauge flag;
- validation: consistent marker-local geometry and sufficient distinct-frame support.

#### `BundleAdjustmentFrameMarkerObservation`

- identity: `(frameIndex, markerObservationPosition)`, preserving marker multiplicity;
- relation: exactly one frame and one marker;
- constants: ordered observed 2D points, marker-local 3D points, persisted `T_cm,ij`, source/profile, quality/gate metadata;
- validation: equal non-empty point counts, at least four pairs initially, finite values, valid intrinsics/pose, compatible geometry.

#### `FrameIndexedBundleAdjustmentProblem`

- provenance: session/schema/app/solver/config/policy;
- immutable ordered frames, markers, observations, components, gauge, solver options;
- variables: only frame and marker poses;
- constants: intrinsics, object/image points, metadata.

#### `FrameIndexedBundleAdjustmentResult`

- optimized frame/marker poses, solver status, termination reason, diagnostics, residuals, exclusions, provenance;
- separate diagnostic artifact, never written into source NDJSON;
- validation: finite poses, gauge consistency, complete metrics, deterministic ordering.

## 6. Mathematical problem

For frame `i`, marker `j`, point `k`:

```txt
p_m,jk = [X, Y, Z]^T                       marker-local mm
u_ijk  = [u, v]^T                          observed px
T_wc,i = (R_wc,i, t_wc,i)                  variable
T_wm,j = (R_wm,j, t_wm,j)                  variable/fixed gauge
K_i    = (fx_i, fy_i, cx_i, cy_i)          fixed

p_c,ijk = transpose(R_wc,i) *
           (R_wm,j * p_m,jk + t_wm,j - t_wc,i)
         = [x, y, z]^T

u_hat = fx_i * x / z + cx_i
v_hat = fy_i * y / z + cy_i
r_ijk = [u_hat - u, v_hat - v]^T

min sum rho_Huber(||r_ijk||^2; delta)
```

The residual sign is predicted minus observed. There is one 2D block per point: four corners yield four blocks/eight scalar residuals. Frame, marker, observation, point order, and multiplicity remain persisted order.

No distortion is applied or optimized initially, matching current PnP's zero distortion. Intrinsics, object points, marker size, and scale remain fixed.

### Domain handling

- Reject before solving any observation with non-finite data, mismatched counts, invalid intrinsics, or initial `z <= depthEpsilonMm`.
- Start `depthEpsilonMm` at `1e-6` mm as only a numerical positivity guard.
- If an iterate gives non-finite projection or invalid depth, residual evaluation fails; do not clamp depth or fabricate a penalty.
- Report evaluation failure separately from non-convergence.

### Huber loss

Start with Huber `delta = 2.0 px` per 2D point block. This is tied to the current scanner's 2 px per-frame reprojection threshold, not copied from the reference's 1 px configuration. Persist delta and residual granularity. Huber changes influence, not membership; a second outlier pass is out of scope.

## 7. Parameterization

| Option | Benefits | Costs | Decision |
|---|---|---|---|
| Angle-axis + translation (6) | Minimal; compatible with persisted Rodrigues and reference 6-value blocks; simple AutoDiff/bridge | Conditioning near pi; matrix conversion required | Recommended for 19B–19E |
| Quaternion + translation (7 ambient/6 tangent) | Stable composition; natural matrix initialization | Requires manifold, normalization, sign canonicalization | Fallback if angle-axis tests expose conditioning issues |
| SE(3) local parameterization | Explicit tangent-space updates | Custom manifold/Jacobians and highest maintenance | Deferred |

Initialize angle-axis from the authoritative explicit matrix. Matrix-to-angle-axis is representation conversion, not pose estimation. Retain the persisted vector for diagnostics. Validate finiteness, determinant near 1, and orthonormality before conversion. Mixed rotation-radian/translation-mm scaling must be tested. Euler angles are not allowed.

## 8. Gauge

Known object points fix scale, but a common world rigid transform leaves all projections invariant: a 6-DOF SE(3) gauge.

- Fixing a marker produces a marker-relative world suitable for relative geometry.
- Fixing the first camera is valid but less aligned with current outputs.
- Fixing both generally over-constrains the problem unless their relation is an exact measurement.

The first experiment fixes exactly one marker:

```txt
T_wm,base = identity
```

This identity defines the coordinate frame; it is not a fallback initializer.

Base policy: build selected bipartite components; choose the eligible component with most retained observations (deterministic ties); among its markers meeting minimum distinct-frame support, choose the smallest marker ID; persist the policy and ID. M0 may be selected but is never special-cased. If the lowest expected ID is unavailable, choose the next eligible ID. If none exists, fail explicitly.

## 9. Initialization

Reference symbols confirm base-marker, per-frame, processing-order, marker-from-frame, PnP recomputation, and robust-average initialization concepts. Exact formulas/order are unknown.

DentalScanner builds a bipartite graph with frame nodes, marker nodes, and observation edges carrying persisted `T_cm,ij`. Starting at `T_wm,base = I`:

```txt
known T_wm,j + T_cm,ij => T_wc,i = T_wm,j * inverse(T_cm,ij)
known T_wc,i + T_cm,ij => T_wm,j = T_wc,i * T_cm,ij
```

Traverse deterministically by frame index then persisted observation position. A spanning-tree edge first initializes a reached state. Recompute states with all reachable finite candidates using:

- translation: component-wise median;
- rotation: quaternion medoid under geodesic distance, deterministic sign and input-order tie-break;
- conversion to solver parameterization only after aggregation.

This aggregate initializes but does not filter residuals. Accumulator A is a comparison and optional cross-check, not the primary initializer: it lacks per-frame cameras, bounds history, and selects a runtime anchor.

Minimum eligibility:

- at least two frames and two markers in a connected component;
- at least four ordered pairs per observation;
- valid fixed intrinsics and persisted `T_cm` for every retained edge;
- each optimized marker in at least two distinct frames;
- every optimized frame has a retained edge;
- one eligible base marker.

A frame may initialize without observing the base directly if a graph path reaches it. Disconnected states never receive identity. Initially optimize only the selected eligible component and report excluded component/frame/marker IDs and counts. If expected markers lie outside, mark the result partial and non-promotable. Under-connected exclusions are explicit; if they make the problem ineligible, fail before solve.

## 10. Observation policies

```txt
ALL      = every structurally valid persisted observation
FILTERED = only persisted preAccumulationGateEvaluated == true
           and preAccumulationGateWouldAccept == true
```

Default: `ALL`. It reproduces the complete pre-accumulator population; the experimental Pre-Gate was aggressive; BA and gate effects must remain separate. FILTERED uses persisted decisions and never reruns thresholds. Both preserve file/frame/marker/point order and frame-local intrinsics.

ALL and FILTERED are separate experiments. Report population and connectivity changes so removal of difficult data is not described as optimizer improvement.

## 11. Residual and robust loss

Implementation requirements:

- one frame pose and one shared marker pose per point residual;
- exact frame intrinsics remain constant;
- no cross-frame correspondence concatenation under one extrinsic;
- residual identity includes frame, marker, observation position, and point index;
- raw pixel residual and robust cost both remain diagnostic;
- initial/final statistics use the same membership;
- Huber neither mutates records nor hides selection.

The reference's variable 4-value simple-radial path is not adopted. Focal, principal point, distortion, object points, and scale stay fixed.

## 12. Solver decision

| Option | Integration/maintenance | Capability and scale | Risk |
|---|---|---|---|
| Ceres | New C++/CMake dependency; static/XCFramework packaging and notices needed | AutoDiff, Huber, manifolds, sparse Schur; appropriate for ~6,024 pose DOF and ~28,000 scalar residuals at 1,000 frames/3,500 four-corner observations | Medium integration risk |
| Original GN/LM | No runtime dependency but substantial numerical code | Must implement Jacobians, damping, block sparsity, robust weighting, convergence; dense normal matrix is inappropriate | Highest correctness/maintenance risk |
| Current libraries | OpenCV/Accelerate already exist | PnP is not BA; Accelerate is linear algebra, not the nonlinear solver | No suitable existing BA backend found |
| External macOS tool | Keeps experiment out of the iOS app | Full Ceres on physical datasets without device runtime pressure | Best initial isolation; schema/math must be shared or cross-validated |

### Primary recommendation

Implement the first executable BA as a self-contained macOS/offline diagnostic tool using project-built, version-pinned Ceres. Keep its model/fixtures independent of live UI. Only after 19E decide separately whether an iOS diagnostic static library/XCFramework is justified.

Official Ceres documentation describes static iOS arm64 builds, current C++17 requirements, an Eigen-only configuration for small/moderate problems, and optional Accelerate BLAS/LAPACK: <https://ceres-solver.readthedocs.io/latest/installation.html>.

Avoid SuiteSparse initially. Ceres uses a BSD-style main license and lists additional bundled-component notices; audit every selected dependency and artifact: <https://github.com/ceres-solver/ceres-solver/blob/master/LICENSE>.

Controls: pin source/checksum; build required architectures; never reuse reference binaries; record Ceres/Eigen/Abseil/compiler/architecture/linear solver/thread count/tolerances/iterations; generate notices; measure app size only if iOS is authorized; add macOS CI before iOS packaging.

Initial deterministic solver profile for 19B:

```txt
trust-region strategy: Levenberg-Marquardt
linear solver: SPARSE_SCHUR with EIGEN_SPARSE
elimination group 0: per-frame camera pose blocks
remaining group 1: shared marker pose blocks
threads: 1
maximum iterations: 100
function tolerance: 1e-6
gradient tolerance: 1e-10
parameter tolerance: 1e-8
```

Eliminating the many camera blocks leaves the small shared-marker system. `DENSE_SCHUR` is permitted only for tiny synthetic fixtures. These are versioned starting values, not backend defaults: 19B must validate or explicitly revise them before 19C. A result is `converged` only when Ceres reports its convergence termination and all output/domain checks pass. Iteration/time limits are non-converged outcomes even if cost decreased; `usableButNotConverged` remains diagnostic and non-promotable.

### Fallback

If Ceres blocks 19B, use a small deterministic LM kernel only as a synthetic oracle with finite-difference Jacobian checks. Do not scale a dense prototype to physical sessions. A custom physical-scale backend requires separate block-sparse Schur review.

## 13. Failure handling

Fail before solving for unsupported/incomplete schema, invalid integrity, missing/invalid intrinsics, non-finite/malformed poses or points, inconsistent geometry, no base, insufficient connectivity/support, invalid initial depth, or uninitialized selected states.

Distinct outcomes:

```txt
notRun
converged
usableButNotConverged
evaluationFailure
numericalFailure
iterationLimit
cancelled
```

Emit only finite, gauge-consistent results with termination reason. Failure never modifies NDJSON, accumulator, scan, STL, reports, or live state. A failed/partial B never replaces A or claims improvement.

## 14. Diagnostics schema

Future output reports:

```txt
capture and schema provenance
algorithm/config/backend/version/architecture
observation and gauge policies; base marker/component
solver status; converged; termination; iterations; runtime
initial/final cost and reduction
frames/markers/observations/corners considered and optimized
residual count
initial/final RMS
per-frame and per-marker RMS
maximum and P50/P90/P95/P99 residual
invalid depth and exclusions by reason
disconnected components and excluded IDs
initialization disagreement
rotation matrix/vector consistency
determinism tolerances and repeated-run deltas
```

A versus B reports marker sets, missing markers, pairwise distances/deltas, pairwise relative-rotation deltas, and population/connectivity differences. Ground-truth error is reported only with measured truth. Lower training residual alone is not “BA better.”

## 15. Synthetic validation plan

Use deterministic truth with at least three cameras, four markers, non-trivial rotations/translations, known per-frame intrinsics, mathematical projections, seeded noise, and controlled initial perturbation. Identity-only fixtures are prohibited.

Required cases:

1. transform composition/inversion;
2. hand-computed projection and residual sign;
3. AutoDiff/analytic Jacobian against central finite differences;
4. exact noiseless recovery;
5. approximate seeded-noise recovery;
6. global-frame invariance and canonical fixed gauge;
7. gauge removal/no unexpected rank deficiency;
8. frame not seeing base but connected through another marker;
9. disconnected component diagnosed, never identity-initialized;
10. invalid intrinsics;
11. negative/near-zero depth;
12. non-finite 2D/3D corner;
13. mismatched point arrays;
14. bad finite initialization and defined convergence/failure;
15. large outlier with and without Huber, without deletion;
16. canonical persisted traversal despite container ordering;
17. repeated-run determinism;
18. exact ALL/FILTERED populations and connectivity reporting;
19. marker multiplicity and corner order through schema adapter;
20. explicit matrix initialization not replaced by persisted Rodrigues vector.

Fixtures record seed, distribution, perturbation, truth, and tolerance. Rotation error is a relative-rotation geodesic angle, not Euler differences.

## 16. Physical A/B plan

After synthetic acceptance, use the external physical session without tracking it:

1. validate schema/integrity/provenance;
2. run A and B on identical ALL input;
3. run B twice fresh and verify determinism;
4. report convergence, residuals, exclusions, connectivity, and runtime;
5. compare pairwise relative geometry;
6. run FILTERED separately and report membership/connectivity changes;
7. use absolute-error claims only with measured ground truth;
8. retain known visual marker issues as operator context, not causal labels.

No automatic “BA better” verdict is produced.

## 17. Incremental implementation phases

### 19A — Investigation and specification

This document. Acceptance: conventions, model, solver, failures, diagnostics, tests, and open questions are explicit; no production code changes.

### 19B — Synthetic mathematical core

Deliver isolated transform/projection/residual/Huber/gauge code and non-trivial ground-truth tests. Accept when exact/noisy recovery, Jacobian, gauge, depth, outlier, connectivity, and determinism tests pass without app/NDJSON integration.

Spec 20 physical maturity review should precede any decision to promote a selected real-session population, but it does not block synthetic math work after explicit 19A review and does not change the 19B acceptance criteria.

### 19C — Schema-1 NDJSON to BA problem

Deliver a streaming adapter preserving identities, order, intrinsics, points, pose, policy, and provenance. Accept when fixtures prove explicit-matrix initialization, ALL/FILTERED membership, validation, and components.

The adapter must support an explicit, versioned membership policy. Initial required policies remain `ALL` and persisted Pre-Gate `FILTERED`. A future `captureMaturitySelected` policy may be added only after Spec 20 physical validation and must identify policy, mode, thresholds, selected frame/observation IDs, and connectivity. It must never be silently substituted for `ALL`.

### 19D — Synthetic accumulator A versus BA B

Deliver deterministic A/B runner and machine-readable result. Accept when A/B start fresh, consume declared data, expose metrics, and B has no export effect.

### 19E — Offline physical-session execution

Run external physical ALL first, FILTERED second. Accept with complete integrity, convergence/failure, runtime, determinism, residual, connectivity, and relative-geometry reports; commit no artifact.

### 19F — Diagnostic accumulator-versus-BA STL export

Produce separately named/provenanced offline diagnostic STLs from semantically comparable A/B states. Accept only with tested transforms and unchanged normal export.

The pre-BA diagnostic ALL-versus-Pre-Gate-FILTERED replay STL exporter is implemented as reusable infrastructure. It proves common-marker coordinate normalization, existing marker-model reuse, manifest provenance, and isolated diagnostic artifact naming. This does **not** complete 19F: no BA result exists yet, and accumulator-versus-BA semantic-state equivalence and STL output remain pending.

The Spec 20 maturity artifact is also pre-BA infrastructure: it can explain which frames are redundant or disconnected before 19C/19E, but it contains no optimized pose and cannot complete 19B, 19C, or 19F.

### 19G — Outlier and pose-graph evaluation

Evaluate second-pass outliers and/or relative graph separately. Each needs independent membership, thresholds, metrics, failure behavior, and review.

## 18. Explicit non-goals

```txt
online/runtime optimization or ScannerViewModel changes
live accumulator inputs/algorithm
Pre-Gate criteria/order/blocking or Experimental Gate
PoseEstimator/OpenCV/per-frame PnP
legacy concatenated PnP bypass
readiness/finalization/Best Final Pose Candidate
ExportGate/normal STLExporter
camera/focus/profiles/4K
focal/principal-point/distortion optimization
marker scale/object-point optimization
pose graph or second outlier pass in the first BA
extra circles, YOLO/AI, four-corner RANSAC
Python comparator integration
```

## 19. Acceptance criteria

- Transform conventions/compositions and residual equation are explicit.
- Reference claims retain evidence classifications and uncertainty.
- Units, sign, depth, parameterization, gauge, initialization, and disconnected behavior are defined.
- Exactly one marker is fixed by deterministic policy; no hidden identities or M0 special case exist.
- ALL/FILTERED are offline policies with ALL default.
- Any future maturity-selected BA population is explicit, versioned, and physically validated; it never replaces ALL silently.
- Huber pixel delta is justified; no second outlier pass is implied.
- Ceres offline and the fallback are evaluated with dependency controls.
- Non-trivial truth tests cover required success/failure modes.
- 19B–19G have independent acceptance gates.
- Live pipeline and normal export remain unchanged.
- No local reference or physical/runtime artifact is tracked.

Implementation starts only after review.

## 20. Open questions

1. Which pinned Ceres release/dependency set fits macOS CI? (19B)
2. Direct AutoDiff blocks or a project pose abstraction above Ceres? (19B)
3. Real-data SO(3) and matrix/vector consistency tolerances? (19C)
4. Keep single-planar-marker frames as weak or exclude configurably? (19C/19E)
5. Physical-session iteration/time limits after profiling? (19E)
6. Does 2 px Huber generalize against held-out geometry? (19D/19E)
7. Solve disconnected components independently for diagnostics? (after 19E)
8. Is iOS packaging justified after offline evidence? (after 19E)
9. Which exactly comparable state drives diagnostic STL B? (19F)
10. Do graph edges or second-pass outliers help after pure BA baseline? (19G)
11. After Spec 20 physical validation, should 19C add a maturity-selected policy, and should it use STRICT per-marker or whole-frame membership?

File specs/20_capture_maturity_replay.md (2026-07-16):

# 20 — Offline Capture Maturity Replay

## Status

Diagnostics-only offline replay implemented for schema-1 scan sessions. Physical execution against the existing real session remains pending.

This specification does not authorize changes to live progress, live readiness, Pre-Gate blocking, accumulation, finalization, or export. It establishes an observable capture-maturity model before any live behavior is reconsidered.

## 1. Objective

Determine, from an already persisted frame-indexed session, when the scan acquired enough geometrically distinct support rather than merely accumulating repeated observations.

The replay answers, separately for `ALL` and persisted Pre-Gate `FILTERED` populations:

```txt
how many raw marker observations existed
how many observations were structurally usable
how many viewpoints were geometrically distinct
how many frames contributed selected observations
which marker reached maturity last
whether the expected frame-marker graph was connected
when marker and global maturity were first reached
how early the existing live progress/finalization signals occurred
```

The primary result is `STRICT`. An adapted `REFERENCE_LIKE` result is additional diagnostics and never replaces `STRICT`.

The detailed artifact is:

```txt
<scan-basename>_capture_maturity_replay.json
artifactSchemaVersion = 1
```

It contains no image data and does not modify the source NDJSON, scan, STL, report, or diagnostics files.

Encoding uses `JSONEncoder` with `prettyPrinted` and `sortedKeys`; output is written atomically. The exporter refuses source-artifact collisions and repeated runs over identical input/configuration must produce identical bytes.

## 2. Physical motivation

A real scan observed outside the repository had approximately:

```txt
duration                              44.4 s
frames processed                      1,331
marker observations                   4,619
expected markers                      M0, M1, M2, M3
all markers seen                      0.07 s
all markers exportable                1.93 s
experimental angle diversity ready    false
```

Capture continued for more than 42 seconds after every marker became exportable, while normal finalization reported no focus-accepted frames and eventually exported through its maximum-duration fallback. This is physical motivation, not a tracked test fixture and not proof of a specific cause.

The same session family also showed large differences between current-accumulator `ALL` and persisted Pre-Gate `FILTERED` replay geometry. That evidence does not approve live blocking and does not establish that `FILTERED` is better.

Therefore:

- do not equate "all markers exportable" with geometric maturity;
- do not solve maturity by increasing only a raw frame counter;
- do not activate Pre-Gate blocking from this experiment;
- do not connect the offline metric to live progress until physical validation is complete;
- do not claim that maturity selection replaces bundle adjustment.

## 3. TMarker authorization

The locally available TMarker material was inspected under the previously established owner authorization.

Repository rules still apply:

- `_local_reference/` remains read-only and untracked;
- no reference binary, framework, model, asset, geometry, credential, endpoint, authentication material, or physical capture enters Git;
- DentalScanner has no runtime dependency on the reference;
- third-party libraries remain subject to independent license/build review;
- reusable behavior is reimplemented as an original DentalScanner diagnostic design;
- conclusions retain explicit evidence classifications.

The reference executable is encrypted (`cryptid = 1`). Configuration and symbols can establish values and architecture, but they do not expose the exact formulas or call order of the protected implementation.

## 4. TMarker evidence

### Material inspected

The targeted investigation used:

- `_local_reference/tmarker_new/T-Marker 1.8.4/Payload/TruMarker.app/CommonConfig.json`;
- `_local_reference/tmarker_new/T-Marker 1.8.4/Payload/TruMarker.app/DeviceConfig.json`;
- `_local_reference/tmarker_new/T-Marker 1.8.4/Payload/TruMarker.app/YoloConfig.json`;
- the main `TruMarker` arm64 Mach-O symbol/string tables;
- `en.lproj/Localizable.strings`;
- `_local_reference/analysis/full_reference_analysis.md`;
- `research/reference_scanner_pipeline_findings.md`;
- the existing local IPA inventory/tree reports.

No reference file was modified or copied into the repository.

### Configured values

| Configuration | Value | Scope and likely role | Classification |
|---|---:|---|---|
| `MarkerConfig.kProgressMarkerCount` | 3 | Reference progress-marker population; not applicable as a DentalScanner expected-marker count | CONFIRMED BY CONFIGURATION |
| `MarkerConfig.kOptimizationMarkerCount` | 2 | Minimum marker support associated with reference optimization/frame handling | CONFIRMED BY CONFIGURATION |
| `MarkerConfig.kMinValidFramesPerMarker` | 65 | Minimum valid-frame support per marker | CONFIRMED BY CONFIGURATION |
| `AngleDiversityConfig.kMinAngularSeparationDeg` | 1.5 deg | Minimum separation associated with per-marker viewpoint diversity | CONFIRMED BY CONFIGURATION |
| `AngleDiversityConfig.kTargetAngularStdDeg` | 4.5 deg | Desired per-marker angular dispersion target | CONFIRMED BY CONFIGURATION; interpretation supported by symbols |
| `ProgressHoldConfig.kTargetOptFrames` | 300 frames | Session/global optimization-support or progress-hold target | CONFIRMED BY CONFIGURATION |
| `AngleDiversityConfig.kHalfProgressFraction` | 0.5 | Dynamic-progress/relaxation control | CONFIRMED BY CONFIGURATION |
| `AngleDiversityConfig.kDynamicStepUpFactor` | 0.25 | Dynamic-progress step factor | CONFIRMED BY CONFIGURATION |
| `AngleDiversityConfig.kDynamicStepUpMinDeg` | 0.1 deg | Lower angular step bound | CONFIRMED BY CONFIGURATION |
| `AngleDiversityConfig.kStdRelaxMarginDeg` | 0.25 deg | Angular-dispersion relaxation margin | CONFIRMED BY CONFIGURATION |
| `AngleDiversityConfig.kDynamicRelaxFactor` | 0.8 | Dynamic threshold relaxation multiplier | CONFIRMED BY CONFIGURATION |
| `ProgressHoldConfig.kHoldStartPercent` | 1.0 (`Percent`-named unit) | Progress-hold boundary; exact scale and call semantics unavailable | CONFIRMED BY CONFIGURATION; use semantics UNCERTAIN |
| `ProgressHoldConfig.kHoldIntervalPercent` | 1.0 (`Percent`-named unit) | Progress-hold/update interval; exact scale and call semantics unavailable | CONFIRMED BY CONFIGURATION; use semantics UNCERTAIN |

The 65, 1.5-degree, 4.5-degree, and 300-frame values are real configured values, but their exact protected implementation cannot be inferred from the JSON alone.

### Symbols and architectural evidence

| Evidence | Supported conclusion | Classification |
|---|---|---|
| `TM::Record::CountProgress(Frame)` | Progress is computed from a processed frame object, not only elapsed time | CONFIRMED BY SYMBOL |
| `AssessFrameValidity(Frame&, FrameContainer const&)` | A validity assessment exists before retained progress/optimization use | CONFIRMED BY SYMBOL |
| `IsDiversityValid(Frame const&, FrameContainer const&)` | Diversity is an explicit validity dimension | CONFIRMED BY SYMBOL |
| `ComputeAngularStdDeg(FrameContainer const&, markerId)` | Angular dispersion is computed per marker | CONFIRMED BY SYMBOL |
| `GetMarkerCamUnitVectorsHistory(markerId)`-like symbol | Per-marker marker-camera unit-vector history is exposed by the focused symbol set | STRONG INDICATION |
| `FrameContainer::GetFrameCount(markerId)` | Retained frame support can be queried per marker | CONFIRMED BY SYMBOL |
| `Frame::IsProgressValid` | A frame can be valid or invalid for progress independently of raw presence | CONFIRMED BY SYMBOL |
| `UpdateProgressInformation`, `ClearProgressInformation` | Progress has persistent session state | CONFIRMED BY SYMBOL |
| `RelaxProgressThresholdIfFullyConnected` | A bounded relaxation path is conditioned on connectivity | CONFIRMED BY SYMBOL |
| `FindBaseMarkerIDByValidMarkerCount` | Base-marker selection considers valid support | CONFIRMED BY SYMBOL |
| `OptimizeLogic::Run(FrameContainer, baseMarkerId)` | Optimization consumes the frame-indexed retained container | CONFIRMED BY SYMBOL |
| `InitializeVwcByFrameFromBaseMarker`, `InitializeVwcForFrame` | Camera state exists per frame | CONFIRMED BY SYMBOL |
| `InitializeVwmByIdFromFrames` | Shared marker state is initialized from multiple frames | CONFIRMED BY SYMBOL |
| `BuildRelativeEdges`, `MarkerEdgeCost` | Relative marker connectivity/graph constraints exist | CONFIRMED BY SYMBOL |
| `AddReprojectionResiduals`, `ComputeReprojectionResidual` | Frame-indexed reprojection residuals enter optimization | CONFIRMED BY SYMBOL |
| `RemoveOutliers`, `RecomputeVwcByPnP`, `RobustAverageVbm` | A later outlier/re-estimation path exists | CONFIRMED BY SYMBOL |
| `ceres::Problem`, `ceres::Solve`, `ceres::HuberLoss`, `BAReport` | Ceres, robust loss, and BA reporting are present | CONFIRMED BY SYMBOL |

### TMarker capture-maturity questions

1. **What does the progress bar measure?** It uses frame/progress-validity state with per-marker progress information. The exact aggregation formula is unavailable. `CONFIRMED BY SYMBOL`; exact formula `UNCERTAIN`.
2. **Raw, valid, selected, or optimizable frames?** Symbols distinguish raw frame processing from validity/diversity and retained frame counts. Progress therefore is not a simple raw-detection counter. Whether "valid" and "selected" are the same internal population is `UNCERTAIN`.
3. **How many views per marker?** `kMinValidFramesPerMarker = 65`. `CONFIRMED BY CONFIGURATION`. Whether every count is angularly distinct is `UNCERTAIN`.
4. **How are two views different?** A per-marker unit-vector history and a 1.5-degree minimum angular separation exist. `CONFIRMED BY CONFIGURATION/SYMBOL`; exact comparison and boundary are `UNCERTAIN`.
5. **What represents viewpoint?** The focused symbols strongly indicate retained marker-camera unit vectors per marker. `STRONG INDICATION`; exact direction sign is `UNCERTAIN` and irrelevant to pairwise angles but relevant to bins.
6. **Per marker or anchor?** Angular standard deviation and vector history are keyed by marker ID. `CONFIRMED BY SYMBOL`.
7. **Shared virtual camera/frame pose?** Per-frame camera state exists for optimization. `CONFIRMED BY SYMBOL`. Its direct use in progress is `UNCERTAIN`.
8. **How is angular dispersion calculated?** `ComputeAngularStdDeg` exists per marker and 4.5 degrees is configured. The formula is protected. `CONFIRMED BY SYMBOL/CONFIGURATION`; formula `UNCERTAIN`.
9. **Azimuth/elevation bins?** No supporting config or focused symbol was found. `UNCERTAIN`; DentalScanner bins are an explicit adaptation.
10. **Staged capture?** No confirmed staged/guided-capture architecture was found. `UNCERTAIN`.
11. **Does the slowest marker control global progress?** Per-marker progress values exist, and a complete session must satisfy marker support. Minimum-marker aggregation is a `STRONG INDICATION`, not confirmed implementation.
12. **Can progress reach 100% without diversity?** Diversity validity and progress-valid state are separate explicit concerns, strongly indicating that diversity constrains completion. Exact 100% rule is `UNCERTAIN`.
13. **What prevents early finalization?** Valid-frame support, diversity, optimization target/progress hold, and connectivity-conditioned relaxation all exist. `STRONG INDICATION`; exact conjunction is `UNCERTAIN`.
14. **Minimum capture time?** No explicit minimum-time config or symbol was confirmed. `UNCERTAIN`.
15. **Final stability window?** No exact final-stability window was confirmed. `UNCERTAIN`.
16. **How are thresholds relaxed?** A fully-connected relaxation function and bounded dynamic config values exist. `CONFIRMED BY SYMBOL/CONFIGURATION`; formula/order is `UNCERTAIN`.
17. **Does relaxation affect progress, selection, or BA?** The symbol names place it in progress thresholding, not residual construction. `STRONG INDICATION` that it affects future validity/progress admission, not BA math.
18. **Which frames enter BA?** `OptimizeLogic::Run` consumes `FrameContainer`. `CONFIRMED BY SYMBOL`; exact membership and any later subset are `UNCERTAIN`.
19. **All frames or a diverse subset?** Validity/diversity occurs before container optimization, strongly indicating a retained subset rather than all raw frames. No separate selected-optimization subset symbol was found. `STRONG INDICATION`.
20. **Frames missing some markers?** `kOptimizationMarkerCount = 2` plus pending-invalid-marker symbols strongly indicate partial frames can remain useful. Exact handling is `STRONG INDICATION`.
21. **Disconnected components?** Relative edges, base selection, and fully-connected relaxation exist. `CONFIRMED BY SYMBOL`; exact failure/fallback behavior is `UNCERTAIN`.
22. **Does BA begin only after maturity?** Progress/optimization support are related, but call order is protected. `UNCERTAIN`.
23. **Partial or incremental optimization?** No sufficient evidence confirms incremental BA. `UNCERTAIN`.
24. **How are outliers removed?** Explicit removal, reprojection reporting, camera re-PnP, and robust marker averaging symbols exist. `CONFIRMED BY SYMBOL`; thresholds/order are `UNCERTAIN`.
25. **What should DentalScanner adapt now?** Offline per-marker viewpoint histories, distinct-view selection, explicit connectivity, timeline, slowest-marker diagnostics, and non-premature progress. This is an original DentalScanner adaptation.
26. **What waits for BA?** Optimization membership decisions, joint camera/marker refinement, graph edges, second-pass outliers, and final optimized geometry remain Spec 19 work.
27. **What is not directly applicable?** Reference marker counts, proprietary geometry, extra feature points, AI/model paths, and any protected UI/capture staging are not adopted.

The focused evidence did not establish exact timeout/fallback behavior, operator guidance strings, a minimum capture duration, a final stability window, or the precise role of focus/motion/reprojection in progress admission. Reprojection is confirmed in optimization/outlier symbols, but that is not proof of the capture-progress criterion. These items remain `UNCERTAIN`.

## 5. Evidence classifications

Every artifact entry and policy parameter uses one of:

```txt
CONFIRMED BY IMPLEMENTATION
CONFIRMED BY CONFIGURATION
CONFIRMED BY SYMBOL
STRONG INDICATION
INFERENCE
UNCERTAIN
```

Rules:

- A config proves the value and key, not the protected call site.
- A symbol proves component presence/signature, not formula or call order.
- Multiple aligned config and symbol observations may support `STRONG INDICATION`.
- A DentalScanner design choice inspired by the reference is labeled adaptation or inference.
- No threshold is represented as a precision guarantee.

Important semantic conclusions:

- `65` is a configured minimum of valid frames per marker. Treating it as exactly 65 distinct viewpoints is a conservative DentalScanner adaptation, not confirmed reference implementation.
- `1.5 deg` is a configured minimum angular separation associated with per-marker diversity.
- `4.5 deg` is a configured target angular standard deviation. The presence of `IsDiversityValid` and `ComputeAngularStdDeg` supports interpreting it as desired spread rather than undesired instability, but the exact formula is unavailable.
- `300` is a global optimization/progress-hold target. It is not evidence that BA consumes exactly 300 frames and never independently produces maturity.
- Reference relaxation is confirmed to exist, but the replay's arithmetic schedule is explicitly `REFERENCE_LIKE`, not an implementation claim.

## 6. DentalScanner current behavior

Current live progress primarily reports marker availability/exportability and can reach 100% before offline geometric maturity. Existing diagnostics expose useful milestones, but they are not all semantically exact:

- `timeToAllMarkersSeenSeconds`: first time all expected marker IDs are present in raw per-frame pose results;
- `timeToAllMarkersExportableSeconds`: first throttled sample where every expected marker satisfies current exportable validation;
- `normalFinalizationStartedAtSeconds`: latest uninterrupted normal-finalization start, used only as an available proxy for UI-100 timing;
- `normal_finalization_export_triggered`: export-trigger event, not proof that asynchronous STL writing completed;
- an exact first-UI-100 timestamp and exact STL-write completion timestamp are not currently persisted.

The maturity replay consumes associated diagnostics/report data only when available and labels unavailable or proxy comparisons. It does not hardcode the physical-session values.

No live property is changed:

```txt
scanProgress
captureProgressPercent
expectedMarkerProgressById
normal finalization maturity
```

## 7. Pose/viewpoint convention

DentalScanner's persisted per-frame pose is:

```txt
T_cm = camera-from-marker
p_c  = R_cm * p_m + t_cm
```

This is `CONFIRMED BY IMPLEMENTATION`: OpenCV `solvePnP` output is stored and later passed directly to `projectPoints`.

For viewpoint diagnostics:

```txt
C_m = -transpose(R_cm) * t_cm
d_m = C_m / ||C_m||
```

`C_m` is the camera center in marker-local coordinates, and `d_m` is the unit marker-to-camera direction.

Angular distance:

```txt
theta(a, b) = acos(clamp(dot(a, b), -1, 1))
```

- internal unit: radians;
- public artifact unit: degrees;
- no Euler-angle comparison;
- no use of Rodrigues vector as a viewpoint substitute;
- no special anchor or logic for M0;
- sign reversal would preserve pairwise angular distance but would change azimuth/elevation bin identity, so the confirmed `C_m` direction is used.

Before use, require finite translation, finite 3x3 rotation, approximate orthonormality, determinant approximately `+1`, and camera-center norm above epsilon. Invalid observations are diagnosed, not repaired.

Default numerical checks:

```txt
orthogonality tolerance   1e-5
determinant tolerance     1e-5
vector norm epsilon       1e-9
```

These are DentalScanner numerical guards, not reference thresholds.

## 8. Frame/observation selection

The schema-1 reader remains the integrity and reconstruction authority. The maturity consumer uses an immutable complete-observation callback rather than introducing a second NDJSON parser.

Counts remain distinct:

```txt
sourceObservationCount
policyInputObservationCount
validObservationCount
selectedObservationCount
frameSupportExcludedObservationCount
selectedDistinctViewCount
selectedFrameCount
framesWithOneSelectedMarker
framesWithAllExpectedMarkersSelected
framesWithAllExpectedMarkersObserved
```

Selection preserves:

- physical frame order;
- marker observation order and multiplicity;
- original frame index and capture timestamp;
- persisted explicit rotation matrix and translation;
- marker-local independent histories.

Strategies:

1. `perMarkerObservation` — default `STRICT` strategy. Each marker observation independently adds a distinct view only when sufficiently separated from that marker's selected history.
2. `wholeFrameWhenAnyMarkerHasDistinctView` — adapted `REFERENCE_LIKE` strategy. When a structurally valid frame contains at least one new distinct marker view, all structurally valid policy observations in that frame are retained as selected frame support, while distinct-direction histories remain per marker.

The second strategy is not asserted to be the exact protected reference implementation.

`minimumObservationsPerFrame` defaults to `1`; the reference count of two optimization markers is not transplanted. If an experimental configuration raises this value, otherwise valid observations in a frame with insufficient support are counted as `frameSupportExcluded`, not falsely labeled as angularly redundant.

## 9. Angular diversity

### Distinct-view admission

The first valid view for each marker is selected. A later candidate is compared with every selected direction for the same marker:

```txt
nearestAngle = min(theta(candidate, selectedDirection))
```

It is distinct when it meets the active minimum-separation threshold within the configured numerical tolerance; otherwise it is redundant. A selected view for one marker does not select a distinct view for another marker.

### Angular spread

The DentalScanner adapted spread metric is:

```txt
s          = sum(d_i)
mean       = normalize(s), when ||s|| > epsilon
deviation_i = theta(d_i, mean)
spreadRMS   = sqrt(mean(deviation_i^2))
```

This is persisted as `angularSpreadDegrees`. It is an original stable diagnostic consistent with the reference concept of a per-marker angular standard-deviation target, but it is not claimed to be the protected `ComputeAngularStdDeg` formula.

If the mean direction is numerically undefined because selected directions cancel, `angularSpreadDegrees` is unavailable (`nil` in the Codable model), `angularMeanDirectionDefined` is `false`, angular-spread progress is zero, and the marker cannot satisfy angular-spread maturity. The replay never substitutes a constant preferred direction or a synthetic spread.

Many views concentrated in one small region can satisfy raw count while failing distinct-view count, spread, or coverage.

## 10. Coverage

Coverage is a DentalScanner diagnostic adaptation. No azimuth/elevation-bin mechanism was confirmed in the reference.

Per-marker convention:

```txt
azimuth   = atan2(y, x), range [-180, 180) degrees
elevation = asin(z),     range [-90, 90] degrees
```

Default diagnostic grid:

```txt
azimuth bins    12
elevation bins   6
```

At a pole where horizontal norm is at most epsilon, azimuth is deterministically assigned to `0 deg`. Bin order is elevation index then azimuth index.

The artifact persists:

```txt
coveredBinCount
totalBinCount
coveragePercent
coveredBins
missingBins
```

Default `requiredCoveragePercent = 0`, so coverage is reported but does not gate maturity until physical evidence defines a justified requirement.

## 11. Relaxation

### `STRICT`

- primary result;
- fixed 1.5-degree distinct-view threshold;
- fixed 4.5-degree spread target;
- no threshold relaxation;
- no adaptive promotion to maturity.

### `REFERENCE_LIKE`

This mode demonstrates bounded relaxation using confirmed config values and the confirmed connectivity-conditioned relaxation concept, but its exact schedule is an adaptation.

Initial adapted schedule:

```txt
first threshold                 targetSelectedFrameCount * 0.5
later interval                  targetSelectedFrameCount * 0.25
angular separation update       current * 0.8
angular separation floor        0.1 deg
spread target update            current - 0.25 deg
spread target floor             0.25 deg
precondition                    expected selected graph connected
```

Each event persists:

```txt
previous/current separation
previous/current spread target
frame index
timestamp
selected-frame count
next threshold
reason
reason further relaxation stopped
```

`REFERENCE_LIKE` never mutates or replaces the `STRICT` result.

## 12. Marker maturity

Each expected marker has an independent history and one state:

```txt
notObserved
insufficientValidObservations
insufficientDistinctViews
insufficientAngularSpread
insufficientCoverage
mature
```

Default experimental criteria:

```txt
valid observations             >= 65
distinct selected views        >= 65
angular spread                 >= 4.5 deg in STRICT
coverage                       diagnostic only by default
```

The first condition is based on confirmed valid-frame config. Requiring 65 distinct views is deliberately conservative and classified as an adaptation pending physical validation.

For every marker, persist:

```txt
raw/policy-input/valid/selected/redundant/frame-support-excluded/rejected counts
rejection counts by structural reason
selected direction history
nearest-angle statistics
angular spread
coverage
first observed/distinct/mature timestamps
maturity frame index and state
blocking reason
progress components
confirmed/adapted/uncertain criterion lists
```

Unexpected marker IDs are diagnosed and do not satisfy expected-marker maturity.

## 13. Global maturity

Global maturity requires all of:

```txt
every configured expected marker is mature
expected marker IDs are connected through the selected frame-marker graph
selected support satisfies configured structural requirements
no confirmed global requirement is missing
```

`targetSelectedFrameCount = 300` is reported as optimization-target progress, but reaching it cannot independently make the session mature.

The slowest marker is selected deterministically:

- before maturity: lowest marker progress, with marker ID as tie-breaker;
- after all marker criteria pass: latest maturity timestamp, with marker ID as tie-breaker.

Persist:

```txt
firstTimestampAllMarkersMature
frameIndexAllMarkersMature
firstTimestampGlobalMature
frameIndexGlobalMature
slowestMarkerId
slowestMarkerBlockingReason
matureMarkerCount
selectedFrameCount
selectedObservationCount
optimizationTargetReachedTimestamp
expectedMarkersConnected
globalMaturityState
globalBlockingReason
```

`requireSelectedFrameTargetForGlobalMaturity = true` makes the configured 300-frame target an explicit DentalScanner support gate in the initial experiment. This use is an adaptation, not a confirmed reference formula, and is persisted in the global adapted/uncertain criterion lists. The flag can be disabled in a controlled offline configuration without changing the live app.

No marker, including M0, is a preferred maturity anchor.

## 14. Connectivity

The replay maintains bipartite graphs:

```txt
frame node <-> marker node
```

Graph populations are separated by:

- `ALL` versus `FILTERED`;
- structurally valid observations versus selected observations.

Each observation edge preserves multiplicity for counts while connectivity uses node incidence.

Persist:

```txt
componentCount
largestComponentFrameCount
largestComponentObservationCount
largestComponentMarkerIds
expectedMarkersConnected
disconnectedMarkerIds
isolatedFrameCount
```

A disconnected expected marker blocks global maturity. The replay never assigns an identity or inferred relation to a disconnected component.

## 15. Progress model

Marker progress exposes its components:

```txt
validObservationProgress = min(valid / requiredValid, 1)
distinctViewProgress     = min(distinct / requiredDistinct, 1)
angularSpreadProgress    = min(spread / requiredSpread, 1)
coverageProgress         = min(coverage / requiredCoverage, 1)
markerProgress           = minimum of enabled required components
```

When coverage is disabled, it is reported but contributes a neutral `1.0`.

Global progress is the minimum expected-marker progress plus global connectivity/maturity rules:

```txt
globalProgress <= 0.99 while global state is not mature
globalProgress == 1.0 only when global state is mature
```

`firstTimestampAllMarkersMature` records completion of the per-marker criteria. `firstTimestampGlobalMature` additionally requires connectivity and configured global support and is the milestone used for UI-versus-offline maturity comparison.

This diagnostic is intentionally not wired to the live UI.

## 16. Timeline

Snapshots are emitted deterministically at a configurable interval, default `0.5 s`, using persisted frame timestamps and physical file order. Each interval is represented by the first physical frame that reaches or crosses its elapsed-time boundary; a terminal snapshot is appended when the last frame is not already represented. Timestamp regressions are diagnosed; frames are never sorted or interpolated.

Each snapshot contains:

```txt
timestamp
frameIndex
policy
mode

per marker:
  raw/valid/distinct/redundant counts
  angular spread
  coverage
  maturity state
  progress
  blocking reason

global:
  mature/expected marker counts
  all-markers-mature
  selected frames/observations
  connectivity
  optimization target progress
  global progress
  blocking reason
```

Marker IDs, bin IDs, rejection reasons, and timeline records use stable deterministic ordering. Repeated replay with the same input/configuration must produce byte-identical JSON.

## 17. ALL versus FILTERED

`ALL` includes every persisted marker observation that passes schema reconstruction and maturity structural validation.

`FILTERED` includes only observations whose persisted annotations satisfy:

```txt
preAccumulationGateEvaluated == true
preAccumulationGateWouldAccept == true
```

The gate is not re-executed. Current thresholds are not applied retrospectively. Missing evaluation or decision annotations are counted and excluded from `FILTERED` maturity rather than inferred.

Both policies run `STRICT` and `REFERENCE_LIKE` independently and report:

- source and retained populations;
- selected frames and observations;
- per-marker maturity;
- connectivity;
- timeline;
- slowest marker;
- maturity-time differences.

No result declares `ALL` or `FILTERED` better. In particular, a lower `FILTERED` maturity can mean the persisted gate removed useful coverage; a higher result can mean it removed redundancy. Only physical/ground-truth validation can interpret the change.

## 18. Physical validation

The existing physical session must remain outside Git:

```txt
Scan_2026-07-16_12-30_session.ndjson
```

On device:

```txt
saved scan
-> associated sessionCaptureURL
-> "Executar replay de maturidade da captura"
-> background schema-1 replay
-> ALL/FILTERED, STRICT/REFERENCE_LIKE summaries
-> <scan>_capture_maturity_replay.json
-> share sheet
```

Expected UI states:

```txt
Analisando maturidade da captura...
Replay de maturidade concluído
Falha no replay de maturidade: <actual error>
```

Physical questions:

- Were most of the 1,331 frames redundant?
- Which marker matured last?
- Did M3 actually limit the session?
- Did the UI reach 100% before `STRICT` maturity?
- Did `ALL` and `FILTERED` change maturity and connectivity differently?
- Did persisted `highMotion` rejection reduce useful angular coverage?

Do not report answers until the actual artifact has been executed and inspected.

Associated diagnostics comparison is `availableWithCaveats` or `unavailable`. It must distinguish all-markers-seen, exportable, finalization-start/UI proxy, export-trigger, and unavailable true export-completion time.

When source data exists, persist:

```txt
actualAllMarkersSeenTimestamp
actualAllMarkersExportableTimestamp
actualUI100PercentTimestamp
actualFinalizationStartedTimestamp
actualExportTriggeredTimestamp
actualExportTimestamp
offlineStrictMaturityTimestamp
offlineReferenceLikeMaturityTimestamp
filteredOfflineStrictMaturityTimestamp
ui100ToStrictMaturityDeltaSeconds
exportableToStrictMaturityDeltaSeconds
strictMaturityReachedBeforeExport
```

The source diagnostics timestamps are session-relative while `FrameObservation.timestampSeconds` is a capture clock. The comparison layer must verify/describe its alignment and never subtract incompatible clocks silently.

An external-path macOS CLI is deferred because the current project has no suitable shared macOS target. Do not add an unsafe importer or duplicate the reader. An opt-in XCTest path may consume an externally supplied file without tracking it.

## 19. Explicit non-goals

```txt
live ScannerViewModel progress changes
live scanProgress/captureProgressPercent/expectedMarkerProgressById
live accumulator inputs or MultiFramePoseAccumulator changes
maxSamplesPerMarker or live minimumAngularDiversityRadians changes
Pre-Gate criteria/order or blocking
Experimental Observation Gate changes
PoseEstimator/OpenCV/solvePnP/projectPoints changes
FinalPoseRefiner or legacy concatenated PnP changes
readiness or normal finalization changes
Best Final Pose Candidate behavior
ExportGate or normal STLExporter changes
camera/focus/profiles/4K changes
Python comparator changes
bundle adjustment, Ceres, pose graph, second-pass outliers
intrinsics optimization
guided capture or live staged capture
```

Capture maturity, frame selection, and geometric optimization remain separate concerns.

## 20. Acceptance criteria

- Actual reference config and focused symbols are listed with classifications.
- Protected formulas/call order remain explicitly uncertain.
- The configured 65/1.5/4.5/300 values have documented units, scope, semantics, and caveats.
- `T_cm`, camera center, viewpoint direction, and angular distance are implemented/tested without Euler angles.
- Invalid/non-SO(3) pose data is diagnosed rather than repaired.
- ALL and persisted-decision FILTERED populations are separate.
- Missing gate annotations are diagnosed and never inferred.
- STRICT is primary and never relaxes.
- REFERENCE_LIKE relaxation history is bounded, explicit, and secondary.
- Frames and observations are counted separately.
- Maturity exists independently per expected marker.
- Slowest-marker and global connectivity diagnostics are deterministic.
- Coverage bins are explicitly marked as a DentalScanner adaptation.
- Global progress cannot reach 100% before global maturity.
- Timeline and JSON ordering are deterministic.
- Associated live milestones use exact values or explicit proxies/unavailable states.
- On-device execution is off the main thread and produces one shareable JSON artifact.
- No source/runtime artifact is overwritten.
- No live progress or scan/export behavior changes.
- No reference or physical artifact is committed.
- Bundle adjustment is not implemented; Spec 19B remains pending.

## 21. Open questions

1. Does physical evidence support requiring 65 distinct views, or should valid-frame and distinct-view targets differ?
2. What exact spread metric best correlates with relative marker stability?
3. Should coverage become a maturity gate, and with what sphere partition/threshold?
4. Does per-observation or whole-frame selection better preserve future BA connectivity?
5. How often and under what stall condition should any relaxation occur?
6. Is the first normal-finalization start an adequate UI-100 proxy, or should a future schema persist the exact transition?
7. Should export completion receive a dedicated persisted timestamp?
8. How does ALL/FILTERED maturity correlate with physical ground truth and replay STL geometry?
9. Which selected observation population should feed Spec 19C after offline validation?
10. Should a shared macOS diagnostic target be introduced before physical BA evaluation?
11. Is on-device runtime acceptable for a multi-thousand-observation session, or should repeated per-frame maturity metrics be cached after physical profiling?

No open question authorizes live integration. The next decision follows execution and review of the physical maturity artifact.

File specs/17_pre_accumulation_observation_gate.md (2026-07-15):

# 17 — Pre-Accumulation Observation Quality Gate

## Status

Shadow diagnostics implemented on 2026-07-12.

Blocking is not enabled. The current implementation evaluates and records every per-frame pose immediately before the primary accumulator, but always forwards the original pose array unchanged. Gate ON/OFF behavioral A/B validation remains pending.

## Goal

Prevent observations that fail explicit quality checks from entering `MultiFramePoseAccumulator`, while preserving an A/B control path and leaving export/finalization unchanged.

## Current problem

The current processing order allows this condition:

```txt
an observation may reach the primary accumulator before the experimental quality gate classifies it as rejected
```

As a result, a frame later rejected for focus, frame-mask, distance, or other quality reasons may already influence the primary fused pose.

## Dependency

Spec 16 must exist first so the gate evaluates a complete frame-owned observation rather than disconnected pose values.

The gate must receive immutable observation data and return a classification. It must not mutate the observation or recompute PnP.

## Feature flag

The shadow implementation uses two explicit flags to avoid ambiguous semantics:

```swift
enablePreAccumulationObservationGateDiagnostics = true
enablePreAccumulationObservationGateBlocking = false
```

Rules:

- diagnostics evaluates and records the decision before accumulation;
- blocking remains `false` and no decision filters accumulator input;
- both flag values are recorded in diagnostics and reports;
- enabling blocking requires a separate implementation and validated A/B decision.

## Candidate checks

Evaluate candidates in an explicit, deterministic order:

```txt
expected marker
finite pose
finite intrinsics
frame mask
too close
too far
focus risk
reprojection
motion
```

The implementation spec for each check must define:

- required inputs;
- behavior when metadata is unavailable;
- rejection reason;
- threshold source;
- whether the result is hard reject or diagnostic warning.

Unknown optional metadata must not silently become a hard rejection. For example, unavailable motion support should be reported separately from known bad motion.
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

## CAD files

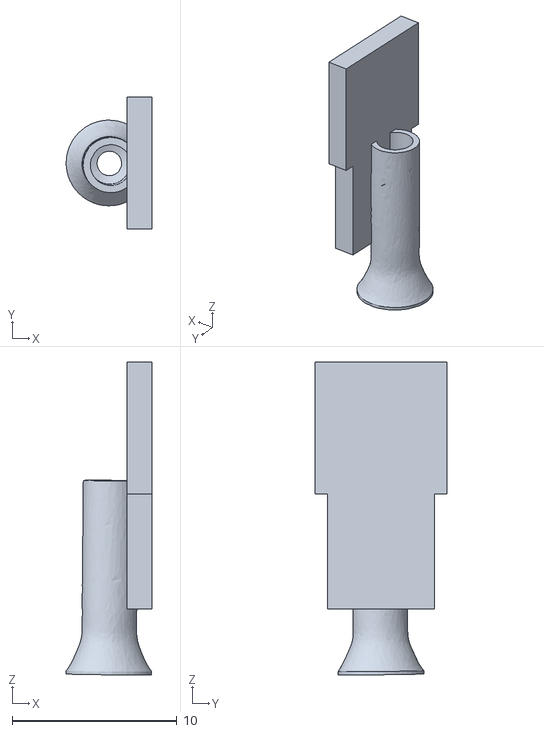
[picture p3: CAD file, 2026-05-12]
DentalScanner/Models/marker_reference_2.stl
5.20 x 8.00 x 19.0

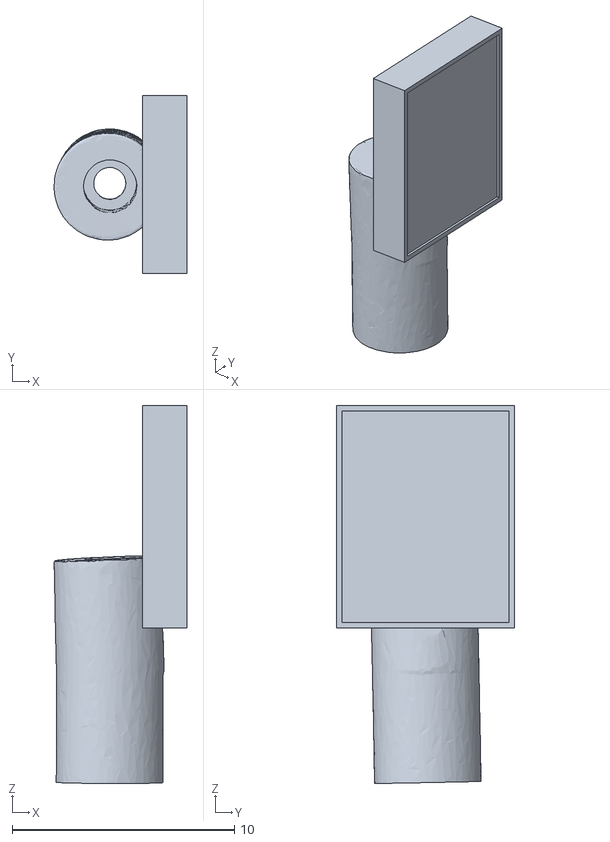
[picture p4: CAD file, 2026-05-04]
DentalScanner/Models/marker_reference.stl
5.97 x 8.00 x 17.0

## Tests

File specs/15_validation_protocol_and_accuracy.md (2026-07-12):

# 15 — Validation Protocol, Comparator Metrics and Accuracy Evidence

## Status

Draft.

This spec defines how DentalScanner results should be validated.

Current comparisons between app-generated STLs measure repeatability, not absolute clinical accuracy.

True accuracy requires a professional reference scan or calibrated ground-truth model.

## Goal

Create a disciplined testing protocol so changes can be judged with data instead of visual impression only.

The protocol should validate:

- camera profile
- distance range
- ROI/frame mask
- useful observations
- angle diversity
- high resolution profile
- focus behavior
- final STL repeatability
- future absolute accuracy against reference STL

## Key Principle

Do not claim absolute accuracy from app-vs-app STL comparisons.

App-vs-app comparisons measure:

```txt
repeatability
stability
consistency
relative drift
```

They do not measure:

```txt
true clinical accuracy
absolute dimensional correctness
implant-level precision
```

---

# Test Sets

## Controlled iPhone 16 Test

Use:

```txt
iPhone 16 normal
physical wide camera
Wide 1.5x
distance 150–180 mm
same marker setup
same lighting
same operator
same scanning path
```

Minimum:

```txt
5 scans per profile
```

Profiles:

```txt
Wide 1.5x
Wide 1.5x Conservative Focus
Wide 1.5x High Resolution Experimental
Wide 1.0x as fallback/control
```

Do not include 2.0x unless specifically testing failure modes.

## Device Comparison Test

Devices:

```txt
iPhone 11
iPhone 13
iPhone 16
iPhone 16 Pro
```

Each:

```txt
same marker
same object/mold
same lighting
same scan instructions
minimum 3 scans per device/profile
```

## Distance Test

For iPhone 16 Wide 1.5x:

```txt
125–150 mm
150–180 mm
180–220 mm
```

Goal:

```txt
find distance band with best repeatability and focus stability
```

## ROI Test

Run scans intentionally:

```txt
markers centered
markers near border
markers partially outside safe ROI
```

Goal:

```txt
confirm frame mask warnings correlate with worse scans
```

---

# Files to Collect

For every scan:

```txt
STL
_report.json
_diagnostics.json
scan screenshot if possible
device/profile notes
```

CSV outputs:

```txt
scan_quality_ranking.csv
stl_comparison.csv
report_diagnostics.csv
scan_diagnostics_summary.csv
marker_report_diagnostics.csv
marker_timing_diagnostics.csv
all_anchors_component_comparison.csv
anchor_summary.csv
```

---

# Comparator Requirements

The comparator should export, without changing STL/ICP logic:

```txt
deviceModelIdentifier
deviceMarketingName
cameraProfileName
deviceQualityClass
requestedZoomFactor
appliedZoomFactor
currentVideoZoomFactor
activeVideoDimensions
activeFormatDescription

distanceGuideState
distanceGuideMessage

frameMaskQualityState
frameMaskQualityMessage
visibleMarkersInsideFrameMaskCount
visibleMarkersViolatingFrameMaskCount
anyMarkerNearFrameEdge

experimentalQualityModeEnabled
experimentalObservationGateEnabled
experimentalAcceptedObservationCount
experimentalRejectedObservationCount
experimentalRejectedByFrameMaskCount
experimentalRejectedByTooCloseCount
experimentalRejectedByTooFarCount
experimentalRejectedByFocusRiskCount
experimentalUsefulAllMarkersReady
experimentalOverallUsefulProgress

angularStdDeg
angleDiversityScore
angleDiversityReady

cameraHighResolutionProfileSelected
cameraAppliedHighResolutionDimensions

referenceCameraMatrixResolutionMismatchWarning
```

Do not change current score formula until enough data exists.

---

# Ranking Interpretation

Good scan candidate:

```txt
low mean distance
low P95
low alignment rotation
low relative marker std
few ROI violations
few focus-risk rejections
high useful progress
good angle diversity
stable intrinsics/profile metadata
```

Warnings:

```txt
HIGH_MEAN_DISTANCE
HIGH_P95
HIGH_ROTATION
HIGH_GEOMETRY_STD
ROI_VIOLATION
LOW_USEFUL_OBSERVATIONS
LOW_ANGLE_DIVERSITY
FOCUS_RISK_REJECTIONS
HIGH_REJECTED_OBSERVATIONS
UNKNOWN_DEVICE_QUALITY_CLASS
```

Do not add these warnings to scoring until enough scans confirm thresholds.

---

# Reference STL

To measure true accuracy, obtain:

```txt
professional lab scan STL
or calibrated industrial scanner STL
or known-dimension test object
```

Then compare:

```txt
DentalScanner STL vs reference STL
```

Metrics:

```txt
mean error
median error
P90
P95
P99
max error
surface heatmap
component/anchor error
rotation delta
translation delta
```

---

# Acceptance Thresholds

Initial repeatability targets:

```txt
mean app-vs-app distance < 0.35 mm
P95 app-vs-app distance < 0.8 mm
alignment rotation < 8 degrees
relative marker geometry score > 99
low ROI violations
usefulAllMarkersReady = true
```

These are not clinical claims.

Absolute accuracy targets should only be defined after reference STL exists.

---

# Test Report Template

For each test batch, create a markdown report:

```txt
test date
app commit hash
device
camera profile
distance range
lighting
marker version
number of scans
best scan
worst scan
ranking summary
main warnings
conclusion
next action
```

---

# Implementation Order

## Commit 1

Add this spec only.

```bash
git commit -m "Add validation protocol spec"
```

## Commit 2

Update comparator columns after app generates new diagnostics.

```bash
git commit -m "Export experimental quality diagnostics"
```

## Commit 3

Add optional markdown report generator to comparator.

```bash
git commit -m "Add scan validation report"
```

---

# Acceptance Criteria

- every test batch includes app commit hash
- every scan includes STL/report/diagnostics
- comparator supports old scans
- missing fields stay blank
- no score changes without evidence
- no absolute accuracy claim without reference STL

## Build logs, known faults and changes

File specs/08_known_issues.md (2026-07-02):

# 08 — Known Issues

## 1. iPhone 16 desfoca/caça foco

Sintoma:

* câmera perde foco durante scan;
* tags ficam borradas;
* pose ainda pode ser detectada;
* inclinação/rotação fica instável;
* STLs podem sair fora da realidade.

Observação:

* travar foco melhorou um pouco;
* ainda precisa foco guiado por ArUco e sharpness gating.

## 2. iPhone 11 parece mais estável

O iPhone 11 apresentou resultados melhores em alguns testes.

Escanear mais perto no iPhone 11 melhorou muito.

Isso sugere que tamanho da tag na imagem é crítico.

## 2.1. iPhones novos precisam de avaliacao por perfil de camera

Antes de escolher configuracao automatica por aparelho, os scans devem registrar e comparar:

```txt
deviceModelIdentifier
deviceMarketingName
cameraProfileId
cameraProfileName
camera fisica selecionada
zoom requested/applied/current
focus/exposure mode
intrinsics fx/fy/cx/cy
```

Perfis `Wide 1.0x`, `Wide 1.5x`, `Wide 2.0x` e variantes `Conservative Focus` sao experimentais. O perfil `Default` deve preservar o comportamento atual, especialmente no iPhone 11.

Resultados iniciais no iPhone 16 indicam:

* `Wide 1.5x` deve ser o perfil recomendado para modelos `iPhone17,*`;
* a câmera deve continuar sendo a wide física traseira, sem macro/ultra-wide/virtual como primeira opção;
* `Wide 2.0x` acusou distância/foco ruins e fica experimental/não recomendado por enquanto;
* distâncias abaixo de aproximadamente 120-125 mm aumentam o risco de perda de foco;
* a faixa inicial recomendada para iPhone 16 com `Wide 1.5x` é 150-180 mm.

O perfil `Wide 1.5x High Resolution Experimental` tenta aplicar 3840x2160 apenas quando selecionado manualmente. Ele nao e recomendado automaticamente; se o formato 4K nao estiver disponivel, o app deve voltar ao formato atual e registrar o fallback.

## 2.2. ROI/frame mask e observacoes uteis ainda nao controlam export

Foi adicionada mascara/ROI por classe de device para detectar markers perto demais da borda da imagem.

Estados esperados:

```txt
ok      -> Markers centralizados
warning -> Evite as bordas da camera / Centralize os markers
unknown -> sem dados suficientes
```

O Experimental Quality Mode agora classifica observacoes brutas como aceitas/rejeitadas usando ROI, distancia, risco de foco e pose finita. Esse progresso util experimental fica em paralelo e ainda nao bloqueia export, readiness ou finalizacao.

Valores iniciais registrados:

```txt
minValidFramesPerMarker = 65
targetOptimizationFrames = 300
```

Ela serve para gerar evidencia em `_report.json`, `_diagnostics.json` e debug emergencial antes de qualquer decisao de produto.

Proximos passos ainda pendentes:

* validar se observacoes uteis correlacionam com scans melhores;
* medir diversidade angular completa;
* investigar PnP/reprojection por canto;
* so depois considerar soft gate por ROI.

## 3. Distância de captura afeta muito

Scans perto ficaram muito mais parecidos com a realidade.

Scans longe tiveram P95/máximo muito maiores no comparador.

A barra de distância precisa ser ajustada para considerar:

* tamanho da tag;
* foco;
* sharpness;
* distância;
* confiabilidade da pose.

Atualizacao:

* a barra lateral agora deve usar thresholds dinamicos de `CameraProfile` / `DeviceQualityProfile`;
* no iPhone 16 com `Wide 1.5x`, 150-180 mm deve aparecer como faixa ideal dentro da barra;
* abaixo de 125 mm deve orientar o usuario a afastar para focar;
* acima de 220 mm deve indicar distancia excessiva.

## 4. Export com 3 markers

Erro recorrente:

```txt
Visualmente parece escanear 4 markers, mas o STL final sai com 3.
```

Isso ocorre cerca de 1 em 10 vezes segundo testes.

Prioridade máxima:

```txt
bloquear export se exportableMarkers.count < expectedPhysicalMarkerCount
```

## 5. Marker 1 instável

Em comparações anteriores, o Marker 1 apareceu como mais instável.

Possíveis causas:

* adesivo torto;
* impressão ruim;
* tag inferior desalinhada;
* fica mais na borda da câmera;
* pareamento/agrupamento do comparador;
* geometria física.

É necessário testar:

```txt
Marker 1 no centro
Marker 1 na esquerda
Marker 1 em outra posição
```

## 6. Bottom tag 6,5 mm instável

No v2, a bottom tag pisca mais.

Ela não deve dominar pose final.

Top tag 8x8 é mais confiável.

## 7. Debug antigo quebrado

O debug antigo causava crash.

Não reativar.

## 8. Comparador STL precisa usar report JSON

Hoje o comparador já compara STL/componentes.

Próxima evolução:

```txt
ler _report.json
comparar poses reais
comparar qualidade
identificar missing markers
comparar foco/sharpness
```

## 9. V1 vs V2 ainda precisa validação objetiva

Ainda não está comprovado que v2 é melhor que v1.

É preciso comparar:

```txt
mesma peça
mesma distância
mesmo celular
mesma iluminação
3 a 5 scans por modo
comparador STL + report JSON
```

## 10. Precisão profissional ainda depende do físico

Para chegar a níveis muito baixos de erro, não basta software.

Também é necessário:

* marker físico preciso;
* impressão/adesivo melhor;
* colagem plana;
* controle de iluminação;
* foco estável;
* câmera calibrada;
* protocolo de captura.
## High resolution profile can reach preview but not progress

The `Wide 1.5x High Resolution Experimental` profile can activate a 3840x2160
camera stream while scan progress remains at 0%. The likely failure modes are
now tracked separately: no frames received, frames not processed, no ArUco
detection, no expected marker IDs, pose rejection, or slow frame processing.

The current fix is diagnostics-first/read-only. It does not change export,
readiness, finalization, solvePnP or STL generation.

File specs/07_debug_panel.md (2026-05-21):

# 07 — Debug Panel

## Histórico

O debug antigo causava crash ao abrir a engrenagem.

Foi descoberto que o botão real da engrenagem estava em outro caminho.

O debug foi reconstruído do zero.

## Debug atual seguro

O debug atual deve usar:

```txt
ScannerDebugPanelView
ScannerDebugSnapshot
Button("DBG")
ScrollView
botão Fechar
bindings seguros
```

## Não reativar

Não reativar:

```txt
debugPanel antigo
debugPanel(isLandscape:)
topControlBar antigo
debugPanelToggleButton antigo
EmergencyScannerDebugPanelView antigo
isDebugPanelExpanded antigo
useSafeDebugPanelOnly antigo
```

Se esses nomes não existirem mais, não recriar.

## Regras

* SwiftUI body não deve calcular métricas pesadas.
* O painel deve receber snapshot seguro.
* Nenhum valor deve crashar a UI.
* nil deve aparecer como `—`.
* NaN deve aparecer como `—`.
* infinity deve aparecer como `—`.
* Não usar force unwrap.
* Não usar `.first!`.
* Não usar `.last!`.
* Não acessar array por índice sem checar.
* `ForEach` deve usar ID estável.
* Não usar `id: \.self` em listas instáveis.

## Conteúdo atual esperado

O debug deve mostrar:

* estado do scan;
* perfil marker;
* readiness message;
* markers atuais;
* export STL básico;
* readiness básico;
* config scan editável;
* marker v2 básico.

## Config scan editável

Parâmetros editáveis esperados:

```txt
markerProfile
minimumCoveragePercentPerTag
minimumGoodFrames
targetGoodFrames
minimumDualTagFramesPerMarker
minimumDualAngularCoveragePercentPerMarker
precisionModeV2
preferDualTagForFinalExport
showDistanceGuide
staticPoseStabilityMode
```

Novos parâmetros de câmera/foco podem ser adicionados depois:

```txt
cameraZoomFactor
manualFocusEnabled
manualLensPosition
autoFocusOnDetectedAruco
lockAfterArucoFocus
minimumAllowedSharpness
minimumPreferredSharpness
arkitAssistedCaptureEnabled
```

## Seções avançadas

Seções avançadas devem ser adicionadas apenas de forma segura:

* Motion/IMU;
* Normal/orientation;
* Static pose stability;
* Planar diagnostics;
* Quality diagnostics;
* ARKit Assist.

Essas seções não devem reintroduzir cálculos perigosos no `body`.

## Regra de ouro

Se uma métrica não estiver pronta ou não for segura, mostrar `—` ou esconder a seção.

Nunca deixar o debug crashar.

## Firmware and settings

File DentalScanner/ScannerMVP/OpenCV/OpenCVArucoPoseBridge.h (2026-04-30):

#import <Foundation/Foundation.h>
#import <CoreVideo/CoreVideo.h>

NS_ASSUME_NONNULL_BEGIN

FOUNDATION_EXPORT NSErrorDomain const OpenCVArucoPoseBridgeErrorDomain;

typedef NS_ERROR_ENUM(OpenCVArucoPoseBridgeErrorDomain, OpenCVArucoPoseBridgeError) {
    OpenCVArucoPoseBridgeErrorOpenCVUnavailable = 1,
    OpenCVArucoPoseBridgeErrorInvalidPixelBuffer,
    OpenCVArucoPoseBridgeErrorUnsupportedPixelFormat,
    OpenCVArucoPoseBridgeErrorPixelBufferLockFailed,
    OpenCVArucoPoseBridgeErrorPixelBufferMissingBaseAddress,
    OpenCVArucoPoseBridgeErrorDetectionFailed,
    OpenCVArucoPoseBridgeErrorInvalidPoseInput,
    OpenCVArucoPoseBridgeErrorPoseEstimationFailed
};

@interface OpenCVArucoImagePoint : NSObject

@property (nonatomic, readonly) double x;
@property (nonatomic, readonly) double y;

- (instancetype)init NS_UNAVAILABLE;
- (instancetype)initWithX:(double)x y:(double)y NS_DESIGNATED_INITIALIZER;

@end

@interface OpenCVArucoMarkerDetection : NSObject

@property (nonatomic, readonly) NSInteger markerId;
@property (nonatomic, copy, readonly) NSArray<OpenCVArucoImagePoint *> *corners;
@property (nonatomic, readonly) double confidence;

- (instancetype)init NS_UNAVAILABLE;
- (instancetype)initWithMarkerId:(NSInteger)markerId
                         corners:(NSArray<OpenCVArucoImagePoint *> *)corners
                      confidence:(double)confidence NS_DESIGNATED_INITIALIZER;

@end

@interface OpenCVArucoPoseResult : NSObject

@property (nonatomic, copy, readonly) NSArray<NSNumber *> *rotationVector;
@property (nonatomic, copy, readonly) NSArray<NSNumber *> *rotationMatrix;
@property (nonatomic, copy, readonly) NSArray<NSNumber *> *translationVector;
@property (nonatomic, readonly) double distanceMm;
@property (nonatomic, readonly) double reprojectionError;

- (instancetype)init NS_UNAVAILABLE;
- (instancetype)initWithRotationVector:(NSArray<NSNumber *> *)rotationVector
                        rotationMatrix:(NSArray<NSNumber *> *)rotationMatrix
                     translationVector:(NSArray<NSNumber *> *)translationVector
                            distanceMm:(double)distanceMm
                     reprojectionError:(double)reprojectionError NS_DESIGNATED_INITIALIZER;

@end

@interface OpenCVArucoDetectionDiagnostics : NSObject

@property (nonatomic, copy, readonly) NSString *dictionaryName;
@property (nonatomic, readonly) NSInteger frameWidth;
@property (nonatomic, readonly) NSInteger frameHeight;
@property (nonatomic, readonly) NSInteger bytesPerRow;
@property (nonatomic, readonly) OSType pixelFormat;
@property (nonatomic, readonly) NSInteger inputChannelCount;
@property (nonatomic, readonly) BOOL convertedToGrayscale;
@property (nonatomic, readonly) NSInteger grayscaleChannelCount;
@property (nonatomic, readonly) NSInteger detectedMarkerCount;
@property (nonatomic, readonly) NSInteger rejectedCandidateCount;

- (instancetype)init NS_UNAVAILABLE;
- (instancetype)initWithDictionaryName:(NSString *)dictionaryName
                            frameWidth:(NSInteger)frameWidth
                           frameHeight:(NSInteger)frameHeight
                           bytesPerRow:(NSInteger)bytesPerRow
                           pixelFormat:(OSType)pixelFormat
                     inputChannelCount:(NSInteger)inputChannelCount
                   convertedToGrayscale:(BOOL)convertedToGrayscale
                  grayscaleChannelCount:(NSInteger)grayscaleChannelCount
                    detectedMarkerCount:(NSInteger)detectedMarkerCount
                 rejectedCandidateCount:(NSInteger)rejectedCandidateCount NS_DESIGNATED_INITIALIZER;

@end

@interface OpenCVArucoPoseBridge : NSObject

@property (nonatomic, readonly) BOOL isOpenCVAvailable;
@property (nonatomic, strong, readonly, nullable) OpenCVArucoDetectionDiagnostics *lastDiagnostics;

- (nullable NSArray<OpenCVArucoMarkerDetection *> *)detectAruco4x4MarkersInPixelBuffer:(CVPixelBufferRef)pixelBuffer
                                                                                 error:(NSError * _Nullable * _Nullable)error
    NS_SWIFT_NAME(detectAruco4x4Markers(in:));

- (nullable OpenCVArucoPoseResult *)estimatePoseForCorners:(NSArray<OpenCVArucoImagePoint *> *)corners
                                    markerSizeMillimeters:(double)markerSizeMillimeters
                                             cameraMatrix:(NSArray<NSNumber *> *)cameraMatrix
                                                    error:(NSError * _Nullable * _Nullable)error
    NS_SWIFT_NAME(estimatePose(corners:markerSizeMillimeters:cameraMatrix:));

- (nullable OpenCVArucoPoseResult *)refinePoseWithObjectPoints:(NSArray<NSNumber *> *)objectPoints
                                                   imagePoints:(NSArray<OpenCVArucoImagePoint *> *)imagePoints
                                                  cameraMatrix:(NSArray<NSNumber *> *)cameraMatrix
                                                         error:(NSError * _Nullable * _Nullable)error
    NS_SWIFT_NAME(refinePose(objectPoints:imagePoints:cameraMatrix:));

@end

NS_ASSUME_NONNULL_END

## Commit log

2026-04-27 Restore desired torch state when camera resumes
2026-04-27 Add multi-frame ArUco pose fusion
2026-04-27 Improve multi-frame pose fusion
2026-04-27 Add ArUco consistency filtering
2026-04-27 Fix STL implant cylinder orientation
2026-04-27 Add minimal home flow and scanner debug toggle
2026-04-27 Add in-app STL viewer
2026-04-27 Pause camera while viewing STL
2026-04-27 Refine STL viewer button style
2026-04-27 Polish STL viewer and ArUco overlay UI
2026-04-30 Use iOS camera intrinsics for solvePnP
2026-04-30 Weight multi-frame pose fusion by quality
2026-04-30 Add STL sharing and polish home screen
2026-05-04 Use marker reference STL for exports
    [marker_reference.stl]
2026-05-05 Add STL rotation debug controls
2026-05-05 Apply global STL rotation correction
2026-05-05 Invert STL correction composition order
2026-05-05 Align reference STL to ArUco tag frame
2026-05-05 Export reference STL from tag poses
2026-05-05 Map reference STL axes to tag frame
2026-05-05 Fix marker STL export flow
2026-05-05 Rotate marker STL in tag plane
2026-05-07 Tighten scan readiness criteria
2026-05-07 Instrument scan ready export flow
2026-05-12 Add dual ArUco marker v2 support
    [marker_reference_2.stl]
2026-05-12 Use v2 reference marker STL for dual exports
2026-05-15 Fix duplicate millimeter formatter
2026-05-15 Improve dual ArUco final frame scoring
2026-05-19 Replace scanner debug gear with safe emergency panel
2026-05-21 Improve camera focus stability diagnostics
2026-05-21 Improve camera focus and sharpness control
2026-05-27 Fix scan diagnostics timing and marker filtering
2026-06-16 Add camera profile evaluation diagnostics
2026-06-19 Tune iPhone 16 wide camera profile
2026-07-02 Add device quality and frame mask diagnostics
2026-07-02 Update distance guide scale for camera profiles
2026-07-02 Enable manual high resolution camera format selection
2026-07-02 Fix high resolution frame processing diagnostics
2026-07-12 Bypass invalid multi-frame PnP for single ArUco refinement
2026-07-12 Add frame-indexed optimization roadmap
2026-07-12 Add frame-indexed observation diagnostics
2026-07-12 Prepare frame observations for deterministic replay
2026-07-12 Fix frame observation rotation persistence build
2026-07-13 Add on-device diagnostic session replay
2026-07-16 Design frame-indexed bundle adjustment experiment
2026-07-16 Add diagnostic replay STL comparison
2026-07-16 Fix diagnostic replay STL test compilation
2026-09-16 ci: validate NDJSON fixtures in watchdog
    Adds deterministic scan-session fixture validation to the Quality Watchdog cheap Ubuntu stage, including positive/negative validator cases and a narrow StrictMode-safe diagnostic fix. Refs #22.
2026-09-16 test: validate repository hygiene policy
    Adds end-to-end self-tests for the real repository hygiene checker and runs them in the cheap Quality Watchdog stage before NDJSON validation and macOS tests/build. Refs #22.
